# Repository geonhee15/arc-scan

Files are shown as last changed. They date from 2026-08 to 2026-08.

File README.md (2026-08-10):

# ARC Scan

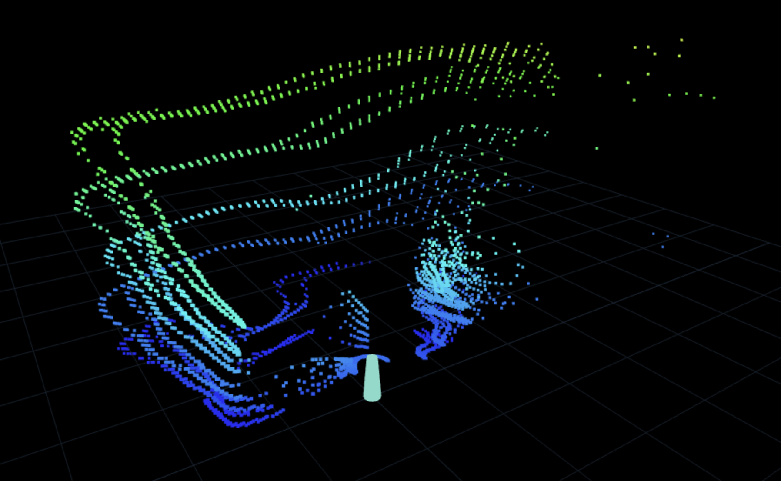
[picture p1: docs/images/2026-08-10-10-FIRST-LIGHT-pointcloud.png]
FIRST LIGHT — 첫 룸 스캔 포인트 클라우드


**A**mbient **R**oom **C**artographer — 회전식 ToF 라이다로 방을 3D 포인트 클라우드로 스캔하는 프로젝트.

VL53L1X ToF 센서 7개를 수직 마스트에 각도를 분산해 장착하고, 서보로 회전시키며
방 전체의 거리 데이터를 수집한다. ESP32가 WiFi 웹소켓으로 스트리밍하고
브라우저에서 three.js로 포인트 클라우드를 실시간 렌더링한다.

## 하드웨어

| 부품 | 수량 | 역할 |
|---|---|---|
| ESP32 DevKit (WROOM-32) | 1 | 메인 컨트롤러 |
| VL53L1X 브레이크아웃 (VL53L0/1XV2 보드) | 7 | ToF 거리 센서 (최대 4m) |
| TCA9548A I2C 멀티플렉서 | 1 | 센서 주소 충돌 해결 (전부 0x29 고정이라 필수) |
| MG996R 서보 | 1 | 회전부 (v1: 180° 스캔) |
| LiPo 503035 500mAh | 1 | 배터리 구동 (마감 단계) |

v2에서 28BYJ-48 스테퍼 + ULN2003A로 교체해 360° 스캔 예정.

## 배선

[docs/wiring.md](docs/wiring.md) 참고.

## 진행 상황

- [x] 0단계: 부품 확인
- [x] 1단계: 센서 1개 + 멀티플렉서 채널 0 인식 성공
- [x] 1단계: 센서 2개 순회 폴링 검증
- [x] 1단계: 7개 전 채널 순회 폴링
- [x] 2단계: WiFi 웹소켓 + three.js 시각화
- [x] 3단계: CAD 설계 완료
- [x] 3단계: 마스트/브라켓 3D 프린팅 + 조립
- [x] 4단계: 풀 조립 스윕 검증 (배선 간섭 없음)
- [x] 4단계: 서보 동기화, 구면좌표 변환, 첫 스캔
- [x] 5단계: 스캔 품질 개선 (1도 스텝 + ROI 4x4)
- [ ] 5단계: 색상 매핑, 배터리 구동, 데모 영상

## 폴더 구조

- `src/` — 단계별 스케치
- `diagnostics/` — 디버깅용 스케치 (I2C 스캐너 등)
- `docs/` — 배선표, 트러블슈팅 기록
- `web/` — 브라우저 뷰어 (three.js)
- `cad/` — 3D 프린팅용 OpenSCAD 소스 + STL

## 삽질 기록

[docs/troubleshooting.md](docs/troubleshooting.md) — 증상 → 원인 → 해결 형식.
같은 보드 조합으로 만드는 사람에게 제일 유용한 문서.

## 빌드 사진

[docs/images/](docs/images/) — 납땜 전 부품부터 채널 검증 시리얼 출력까지 단계별 기록.

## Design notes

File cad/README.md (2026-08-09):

# CAD 파일

OpenSCAD 소스(.scad)가 원본이고 STL은 렌더링 결과물이다.
OpenSCAD는 openscad.org에서 무료 설치. .scad 열어서 상단 변수 수정 →
F6(렌더) → STL 내보내기.

## 파일

- arc_scan_servo_stand.scad / .stl — MG996R 스탠드. 표준 치수 기반이라 **바로 출력 가능**
- arc_scan_mast.scad — 센서 마스트. **실측 4개 값 수정 후 렌더링할 것**
- arc_scan_mast_DEFAULT_DIMS.stl — 미실측 기본값 렌더링. 참고용, 출력 금지

## 마스트 실측 항목 (센서 보드에서 캘리퍼스나 자로)

1. sens_hole_span — 양쪽 나사구멍 중심 간 거리
2. sens_hole_d — 나사구멍 지름 (사용할 나사에 맞게, M2 셀프태핑이면 1.8~2.0)
3. sens_board_len — 보드 긴 변
4. sens_board_wid — 보드 짧은 변

서보 혼 값(horn_*)은 원형 혼 실물 기준으로 확인.

## 출력 설정 권장

- 재료: PLA면 충분
- 레이어: 0.2mm, 인필: 30~40%
- 서보 스탠드: 그대로 바닥에 놓고 출력, 서포트 불필요
- 마스트: 세워서 출력 (바닥 디스크가 베드), 서포트 불필요하게 설계됨.
  틸트면 오버행 최대 30°라 쿨링만 정상이면 깨끗하게 나옴
- 마스트 높이 약 195mm — 출력 시간 수 시간 예상

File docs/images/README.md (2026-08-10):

# 빌드 사진

파일명 형식: 날짜-순번-내용

- 01-xiao-unboxing: XIAO ESP32-C3 개봉 (헤더 미납땜 상태, 이후 WROOM으로 교체)
- 02-vl53l1x-before-solder: VL53L1X 브레이크아웃 납땜 전 (VL53L0/1XV2 공용 기판)
- 03-serial-2ch-success: 2채널 순회 폴링 첫 성공 (천장 ~1720mm)
- 04-breadboard-3ch: 2보드 분리 배치 (컨트롤 보드 + 센서 보드, 3센서)
- 05-serial-3ch-success: 3채널 검증
- 06-serial-4ch-success: 4채널 검증
- 07-serial-5ch-success: 5채널 검증 (복합 배선 버그 해결 직후)
- 08-serial-6ch-success: 6채널 검증 (한 번에 성공)
- 09-breadboard-6ch-full: 6센서 시점 전체 회로 실사 (컨트롤 보드 + 센서 보드 2장 구성)
- 2026-08-10-02-full-assembly: 마스트 완성체 (센서 7개 + 스페이서 + 서보 스탠드, 배선 완료)
- 10-FIRST-LIGHT-pointcloud: 첫 스캔 성공. 방의 벽 모서리, 벽면, 가구, 바닥이
  포인트 클라우드로 재구성됨 (7센서 x 180도 스윕)

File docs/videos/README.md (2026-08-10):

# 빌드 영상

- 2026-08-10-01-mast-first-motion: 마스트 첫 가동. 시리얼 명령(c/각도/s)으로
  서보 위 마스트가 회전하는 최초 동작 확인
- 2026-08-10-02-full-assembly-sweep: 센서 7개 장착 + 배선 완료 상태의 풀 스윕 동작.
  회전 중 배선 간섭 없음 확인
- 2026-08-10-03-first-scan: 첫 스캔 실시간 영상 (스캔 동작 + 뷰어에 점 쌓이는 장면)

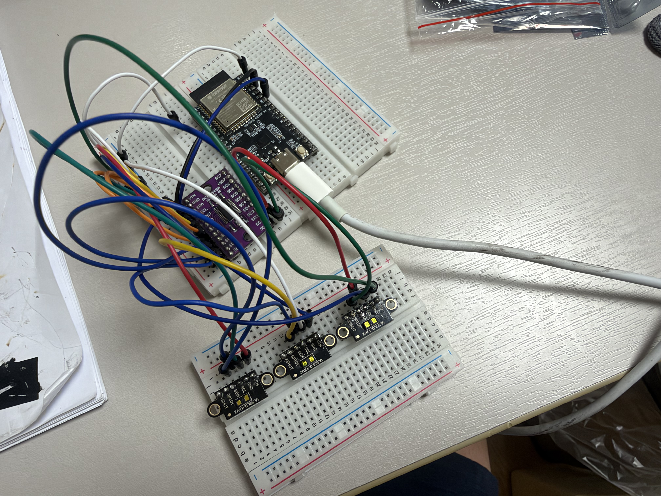
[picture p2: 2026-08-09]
docs/images/2026-08-09-04-breadboard-3ch.jpeg

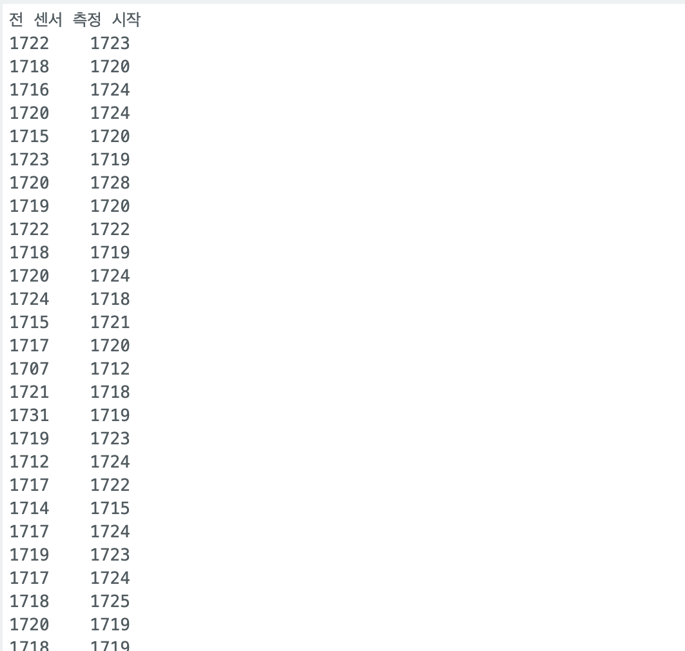
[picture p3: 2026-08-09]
docs/images/2026-08-09-03-serial-2ch-success.png

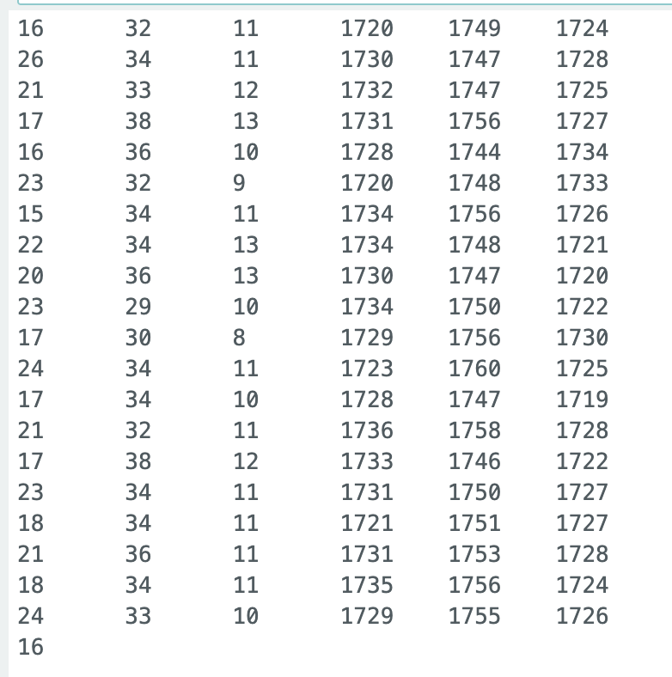
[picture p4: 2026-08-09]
docs/images/2026-08-09-08-serial-6ch-success.png

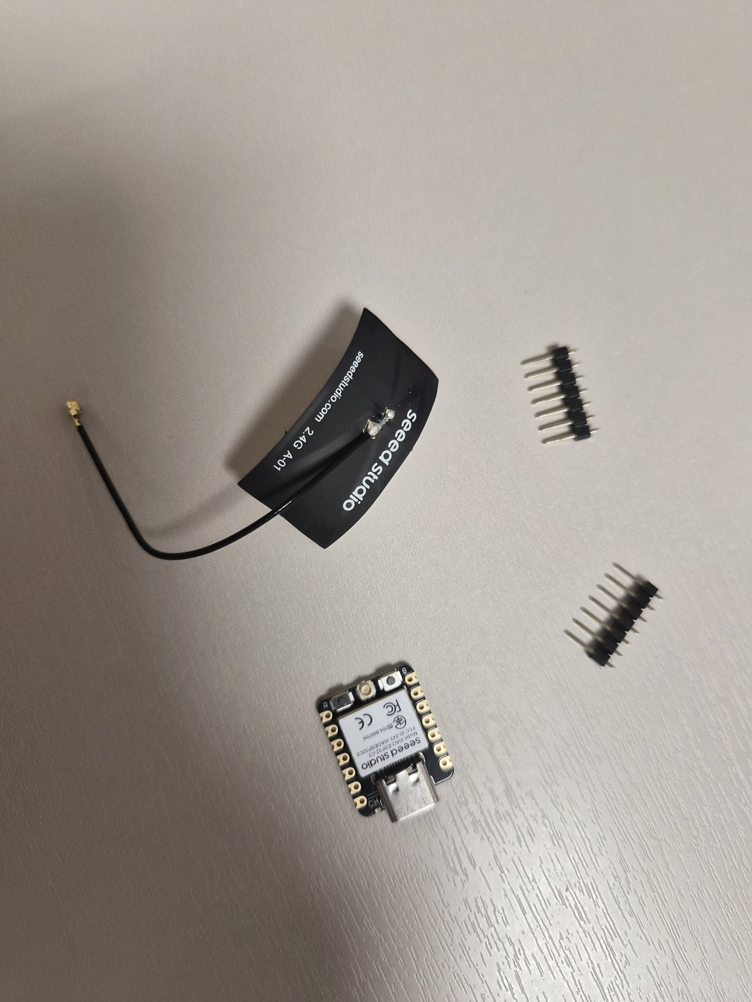
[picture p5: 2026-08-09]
docs/images/2026-08-09-01-xiao-unboxing.jpeg

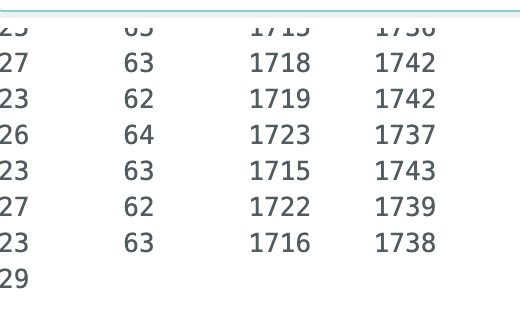
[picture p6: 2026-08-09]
docs/images/2026-08-09-06-serial-4ch-success.png

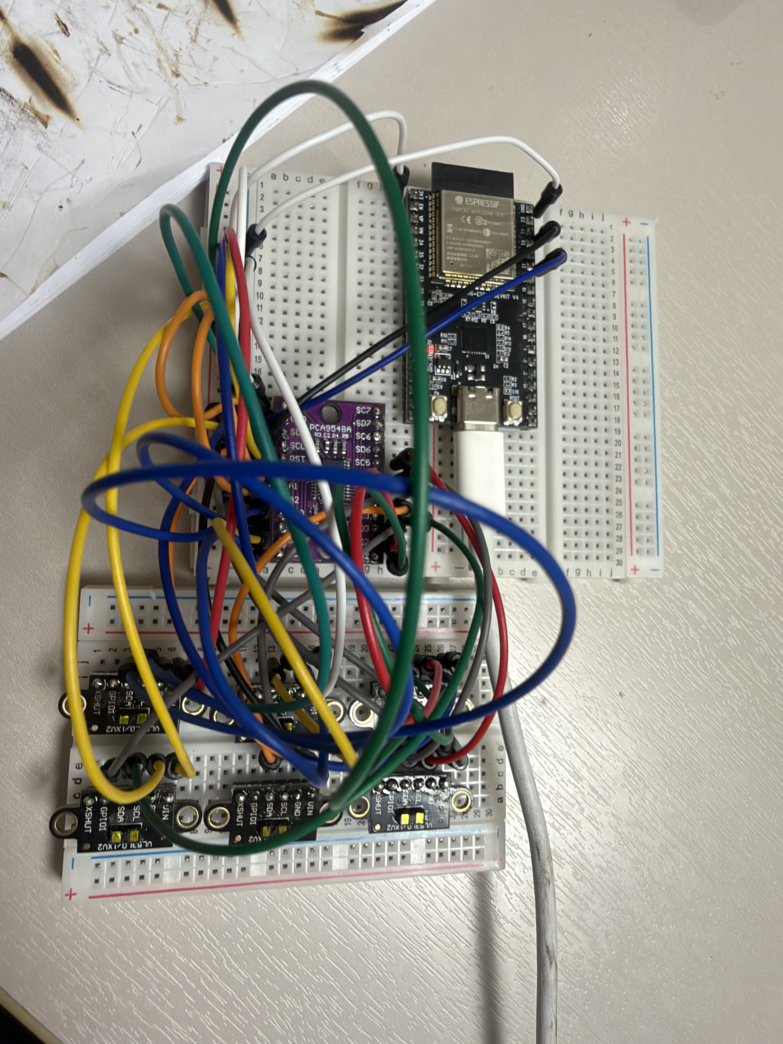
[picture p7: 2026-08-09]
docs/images/2026-08-09-09-breadboard-6ch-full.jpeg

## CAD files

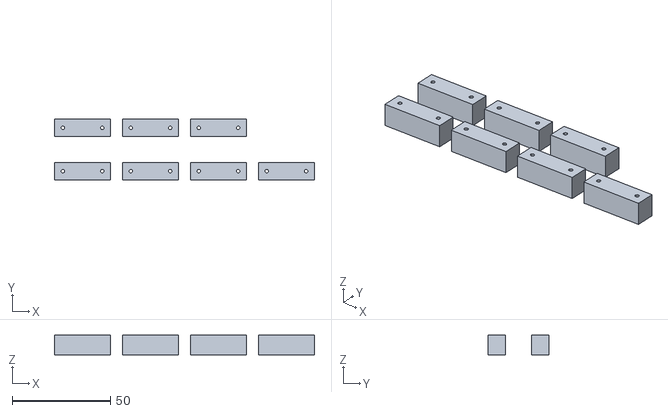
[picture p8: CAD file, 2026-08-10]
cad/arc_scan_sensor_spacer_x7.stl
132.0 x 31.0 x 10.0

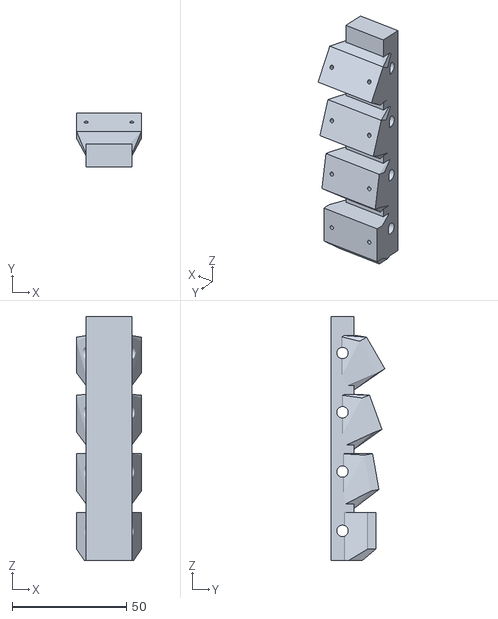
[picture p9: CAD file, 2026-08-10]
cad/arc_scan_mast_TOP.stl
28.5 x 23.6 x 107.0

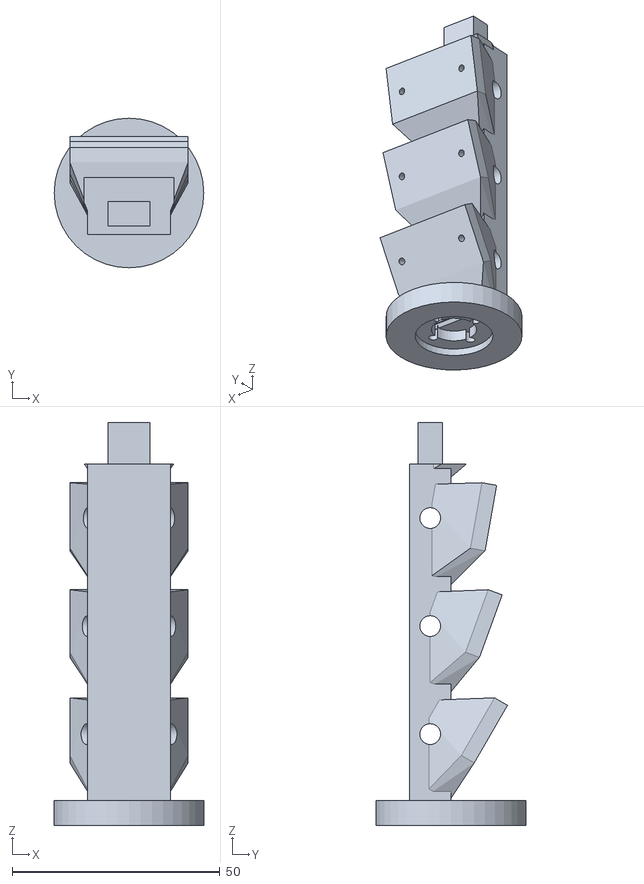
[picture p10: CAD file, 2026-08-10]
cad/arc_scan_mast_BOTTOM.stl
36.0 x 36.0 x 97.0

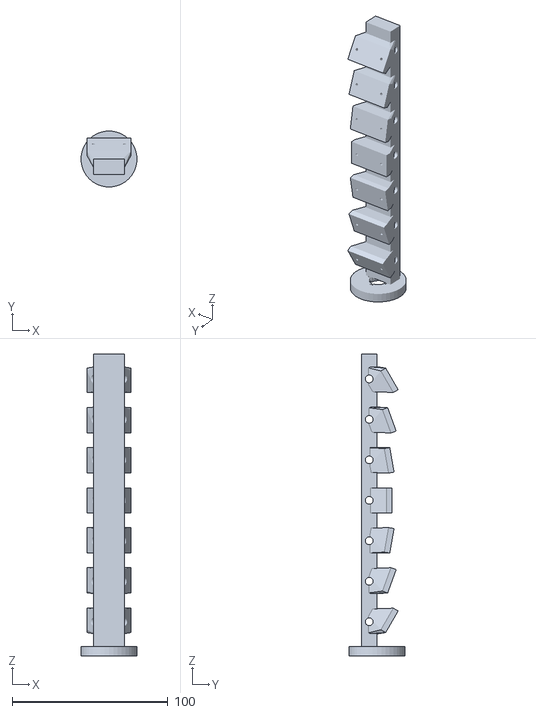
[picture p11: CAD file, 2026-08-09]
cad/arc_scan_mast_MEASURED.stl
36.0 x 36.0 x 194.0

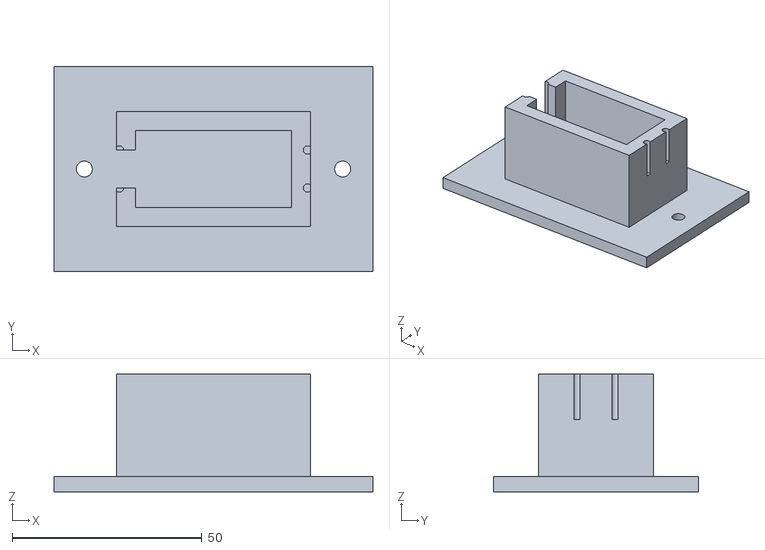
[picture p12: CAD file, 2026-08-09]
cad/arc_scan_servo_stand.stl
84.0 x 54.0 x 31.0

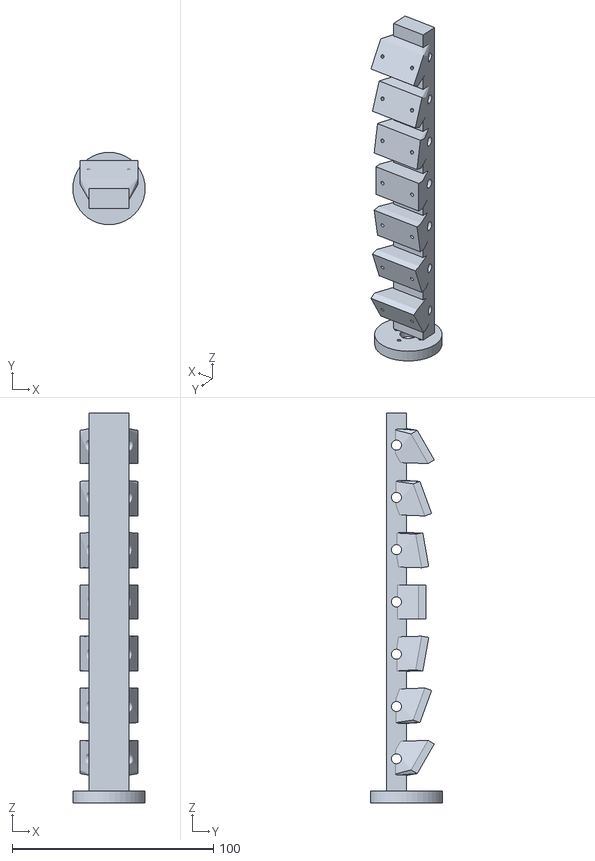
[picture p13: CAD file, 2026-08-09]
cad/arc_scan_mast_DEFAULT_DIMS.stl
36.0 x 36.0 x 194.0

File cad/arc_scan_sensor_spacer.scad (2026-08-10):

// ARC Scan - 센서 스페이서 (헤더 핀 간섭 해결)
// 보드 뒷면과 마스트 장착면 사이에 끼움. 헤더 핀 줄이 지나는 자리에 골.
// 조립: 센서 → M2로 스페이서에 고정 (스페이서 파일럿에 태핑),
//       스페이서 뒷면 → 마스트 장착면에 글루건 접착

$fn = 32;

// 마스트와 동일 실측값
sens_hole_span = 20.0;
sens_board_len = 24.5;
sens_board_wid = 10.0;

spacer_t   = 10;    // 두께 (헤더 핀 길이보다 크게)
pad        = 4;     // 보드보다 큰 여유
chan_w     = 7;     // 헤더 골 폭
pilot_d    = 1.8;   // M2 태핑 파일럿

w = sens_board_len + pad;   // 28.5
h = sens_board_wid + 6;     // 16 (장착면과 동일)

// 7개 한 판에
for (ix = [0:3]) for (iy = [0:1]) {
  n = ix + iy*4;
  if (n < 7)
    translate([ix*(w+6), iy*(h+6), 0])
    difference() {
      cube([w, h, spacer_t]);
      // 헤더 골: 아래쪽 긴 변을 따라 관통
      translate([-1, -1, -1]) cube([w+2, chan_w+1, spacer_t+2]);
      // 파일럿 구멍 2개 (보드 구멍 위치 = 세로 중앙 기준)
      for (s = [-1, 1])
        translate([w/2 + s*sens_hole_span/2, chan_w + (h-chan_w)/2, -1])
          cylinder(d = pilot_d, h = spacer_t+2);
    }
}

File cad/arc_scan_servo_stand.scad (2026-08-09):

// ARC Scan - MG996R 서보 스탠드
// 서보를 출력축이 위를 보게 세워서 고정하는 받침대
// MG996R 표준 치수 기반. 출력 전 본인 서보 실측으로 아래 변수 확인 권장

$fn = 48;

// ===== 실측 확인 변수 =====
servo_len   = 40.7;   // 서보 몸통 길이 (플랜지 제외)
servo_wid   = 20.0;   // 서보 몸통 폭
clearance   = 0.4;    // 끼움 여유
hole_span_l = 49.5;   // 플랜지 나사구멍 간격 (긴 방향, 대각 아님)
hole_span_w = 10.0;   // 플랜지 나사구멍 간격 (짧은 방향)
flange_h    = 27.0;   // 몸통 바닥에서 플랜지 아랫면까지 높이
screw_d     = 2.2;    // 나사 구멍 지름 (M2.5 셀프태핑 기준)

// ===== 스탠드 형상 =====
base_w = 84; base_d = 54; base_t = 4;   // 바닥판
body_w = servo_len + clearance;
body_d = servo_wid + clearance;
wall   = 5;

difference() {
  union() {
    // 바닥판
    translate([-base_w/2, -base_d/2, 0]) cube([base_w, base_d, base_t]);
    // 서보 포켓 벽체 (플랜지가 벽 윗면에 얹힘)
    translate([-(body_w/2+wall), -(body_d/2+wall), 0])
      cube([body_w + 2*wall, body_d + 2*wall, base_t + flange_h]);
  }
  // 서보 몸통 관통 포켓
  translate([-body_w/2, -body_d/2, base_t])
    cube([body_w, body_d, flange_h + 1]);
  // 케이블 빠져나갈 홈
  translate([-body_w/2 - wall - 1, -5, base_t])
    cube([wall + 2, 10, flange_h + 1]);
  // 플랜지 나사 파일럿 구멍 4개
  for (sx = [-1, 1]) for (sy = [-1, 1])
    translate([sx*hole_span_l/2, sy*hole_span_w/2, base_t + flange_h - 12])
      cylinder(d = screw_d, h = 13);
  // 바닥 고정용 구멍 (책상 클램프/나사, 선택)
  for (sx = [-1, 1])
    translate([sx*(base_w/2 - 8), 0, -1]) cylinder(d = 4.2, h = base_t + 2);
}

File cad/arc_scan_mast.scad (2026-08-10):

// ARC Scan - 센서 마스트 (7단 틸트 장착면)
// 채널 0 = 최상단 +30°(위쪽 응시), 채널 6 = 최하단 -30°(아래쪽 응시), 10° 간격
// 장착면은 세로판이며 면의 법선이 전방(+Y)에서 위아래로 틸트됨
// 센서 보드는 장착면에 M2 셀프태핑 2개로 고정, 렌즈가 전방을 바라봄
//
// ★ 출력 전 반드시 실측해서 아래 [실측 필수] 4개 값 수정할 것 ★

$fn = 40;

// ===== [실측 필수] 센서 보드 =====
sens_hole_span = 20.0;
sens_hole_d    = 1.8;
sens_board_len = 24.5;
sens_board_wid = 10.0;

// ===== [실측 권장] 서보 혼 =====
horn_dia          = 20.0;
horn_screw_circle = 14.0;
horn_screw_d      = 2.4;  // 마스트 관통용 (나사는 혼 구멍에 태핑됨)
horn_screw_n      = 4;

// ===== 마스트 형상 =====
tilts      = [30, 20, 10, 0, -10, -20, -30]; // 채널 0(위) → 6(아래)
level_step = 26;     // 장착면 세로 간격
spine_w    = 20;     // 기둥 폭
spine_d    = 10;     // 기둥 두께 (Y)
plate_w    = sens_board_len + 4;   // 장착면 폭
plate_h    = sens_board_wid + 6;   // 장착면 높이
plate_t    = 3.6;    // 장착면 두께
standoff   = 6;      // 기둥 전면에서 장착면까지 거리
base_dia   = 36;
base_t     = 6;
mast_h     = base_t + level_step * 7 + 6;

// --- 세로 장착판: 면 중심이 원점, 법선 +Y, 구멍은 Y로 관통
module face_plate() {
  difference() {
    translate([-plate_w/2, -plate_t, -plate_h/2])
      cube([plate_w, plate_t, plate_h]);
    for (s = [-1, 1])
      translate([s * sens_hole_span/2, -plate_t - 1, 0])
        rotate([-90, 0, 0]) cylinder(d = sens_hole_d, h = plate_t + 2);
  }
}

module mast_body() {
  // 바닥 디스크 (서보 혼 결합)
  difference() {
    cylinder(d = base_dia, h = base_t);
    translate([0, 0, -0.01]) cylinder(d = horn_dia + 0.6, h = 2);
    translate([0, 0, -1]) cylinder(d = 12, h = base_t + 2); // 허브 통과
    for (a = [0 : 360/horn_screw_n : 359])
      rotate([0, 0, a]) translate([horn_screw_circle/2, 0, -1])
        cylinder(d = horn_screw_d, h = base_t + 2);
  }
  // 기둥
  translate([-spine_w/2, -spine_d, base_t])
    cube([spine_w, spine_d, mast_h - base_t]);
  // 7단: 틸트 장착판 + 기둥과 잇는 hull 웨지
  for (i = [0 : 6]) {
    z = base_t + level_step * (7 - i) - level_step/2 + 3;
    hull() {
      translate([0, standoff + plate_t, z]) rotate([tilts[i], 0, 0]) face_plate();
      translate([-spine_w/2 + 2, -spine_d + 1, z - plate_h/2 - 9])
        cube([spine_w - 4, spine_d - 2, plate_h + 9]);  // 아래로 연장: 웨지 밑면 경사를 세워 오버행 완화
    }
  }
}

// hull이 구멍을 메우므로 전체에서 구멍 재차감
module full_mast() {
difference() {
  mast_body();
  for (i = [0 : 6]) {
    z = base_t + level_step * (7 - i) - level_step/2 + 3;
    // 센서 나사 구멍 (틸트 방향 그대로 관통)
    translate([0, standoff + plate_t, z]) rotate([tilts[i], 0, 0])
      for (s = [-1, 1])
        translate([s * sens_hole_span/2, -plate_t - 8, 0])
          rotate([-90, 0, 0]) cylinder(d = sens_hole_d, h = plate_t + 16);
    // 배선 통과 구멍 (기둥 좌우 관통)
    translate([0, -spine_d/2, z]) rotate([0, 90, 0])
      cylinder(d = 5, h = spine_w + 4, center = true);
  }
}
}

// ===== 분할 출력 =====
// part: "full" | "bottom" | "top"  — 상/하 분할로 출력 높이를 절반으로
part   = "bottom";
z_cut  = 87;          // 분할 높이 (4단과 5단 사이 기둥 구간)
plug_w = 10; plug_d = 6; plug_h = 10;  // 결합 플러그 (하단에 돌출)
gap    = 0.3;         // 소켓 여유 (한쪽)

module plug_shape(extra=0, hextra=0)
  translate([-(plug_w+extra)/2, -spine_d/2 - (plug_d+extra)/2, 0])
    cube([plug_w+extra, plug_d+extra, plug_h+hextra]);

if (part == "full") full_mast();

if (part == "bottom") {
  intersection() { full_mast(); translate([-100,-100,-1]) cube([200,200,z_cut+1]); }
  translate([0,0,z_cut]) plug_shape();          // 위로 솟은 플러그
}

if (part == "top") {
  // 절단면이 베드에 닿게 z_cut만큼 내림, 바닥면에 소켓 파기
  difference() {
    translate([0,0,-z_cut])
      intersection() { full_mast(); translate([-100,-100,z_cut]) cube([200,200,200]); }
    translate([0,0,-0.01]) plug_shape(extra=2*gap, hextra=0.4);
  }
}

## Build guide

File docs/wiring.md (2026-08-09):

# 배선표

## 1단계: WROOM + TCA9548A + 센서 1개 (채널 0)

전원은 전부 3.3V. **5V 금지** (TCA, 센서 모두).

### 전원 레일

| 연결 | 대상 |
|---|---|
| WROOM 3V3 | 브레드보드 빨간(+) 레일 |
| WROOM GND | 파란(−) 레일 |

### TCA9548A

| TCA 핀 | 연결 |
|---|---|
| VIN | 빨간 레일 (3.3V) |
| GND | 파란 레일 |
| A0, A1, A2 | 전부 파란 레일 → 주소 0x70 고정 |
| SDA | WROOM GPIO21 |
| SCL | WROOM GPIO22 |

### VL53L1X (채널 0)

| 센서 핀 | 연결 |
|---|---|
| VIN | 빨간 레일 (3.3V) |
| GND | 파란 레일 |
| SCL | TCA SC0 |
| SDA | TCA SD0 |
| GPIO1, XSHUT | 미연결 |

⚠️ 이 센서 보드는 핀 인쇄 순서가 **VIN, GND, SCL, SDA** 순.
SCL이 SDA보다 먼저라 교차 실수하기 딱 좋음 (실제로 한 번 함, troubleshooting.md 참고).

## 예정 (7센서 확장 시)

센서 2~7을 SD1/SC1 ~ SD6/SC6에 동일 방식으로 추가.
채널 번호 = 마스트 위치 매핑: 채널 0 = 최상단 +30°, 채널 6 = 최하단 −30°, 10° 간격.

## 예정 (서보)

| MG996R | 연결 |
|---|---|
| 빨강 | WROOM VIN (USB 5V) |
| 갈색 | 파란 레일 (GND 공통 필수) |
| 주황 (신호) | GPIO13 |

서보 구동 시 전류 스파이크로 보드 리셋되면 서보 전원만 외부 5V로 분리.

### VL53L1X (채널 1) — 채널 0과 동일 패턴

| 센서 핀 | 연결 |
|---|---|
| VIN | 빨간 레일 (3.3V) |
| GND | 파란 레일 |
| SCL | TCA SC1 |
| SDA | TCA SD1 |
| GPIO1, XSHUT | 미연결 |

검증: 두 채널 모두 천장 거리 ~1720mm 일치 출력 확인 (2026-08-09)

### VL53L1X (채널 2) — 동일 패턴, 센서 전용 브레드보드로 분리

센서 3개째부터 두 번째 브레드보드에 센서 전용 배치.
보드 1(WROOM+TCA)의 전원 레일에서 점퍼선 2가닥으로 보드 2 레일 연장,
센서들의 VIN/GND는 보드 2 레일에서 공급.

| 센서 핀 | 연결 |
|---|---|
| VIN / GND | 보드 2 레일 (보드 1에서 연장) |
| SCL | TCA SC2 |
| SDA | TCA SD2 |

검증: 3채널 모두 천장 ~1710~1725mm 일치 (2026-08-09)

### VL53L1X (채널 5, 6) — 동일 패턴

| 센서 | SCL | SDA |
|---|---|---|
| 채널 5 | TCA SC5 | TCA SD5 |
| 채널 6 | TCA SC6 | TCA SD6 |

검증: 7채널 전부 동시 폴링 정상 (2026-08-09). **1단계 완료.**

### 서보 전원 구성 (확정)

| MG996R | 연결 |
|---|---|
| 주황 (신호) | WROOM GPIO13 |
| 빨강 (전원) | 외부 5V (폰 충전기 2A, USB 케이블 개조) — **WROOM VIN 아님** |
| 갈색 (GND) | 브레드보드 GND 레일 (충전기 GND와 공통 접지) |

USB 단일 전원으로는 brownout 발생 (troubleshooting.md 참고).

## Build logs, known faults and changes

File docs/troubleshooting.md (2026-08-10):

# 트러블슈팅 기록

증상 → 원인 → 해결 형식. 날짜순.

## 2026-08-09

### 납땜 브릿지 (XIAO, 센서 헤더)

- **증상**: 납땜 시 옆 핀끼리 납이 계속 붙음
- **원인**: 납 공급량 과다 + 인두를 오래 대고 있음
- **해결**: 납량을 절반 이하로 줄이고, 납선이 녹기 시작하면 1초 안에 뗌.
  이미 붙은 브릿지는 깨끗한 맨 팁으로 핀 사이를 긁어내리면 갈라짐.
  다음 구매: 솔더윅, 플럭스 펜, 0.6~0.8mm 납선

### 센서 초기화 실패

- **증상**: `sensor.init()` 실패, "센서 초기화 실패! 배선 확인" 출력
- **진단**: I2C 스캐너(diagnostics/i2c_scan)로 단계 분리.
  메인 버스에서 0x70(TCA) 발견 → WROOM↔TCA 구간 정상.
  채널 0 열고 0x29 응답 없음 → TCA↔센서 구간 문제로 특정
- **원인**: 센서 보드 핀 순서가 VIN, GND, **SCL, SDA**인데
  SDA/SCL을 교차해서 연결함
- **해결**: 센서 SCL↔TCA SC0, 센서 SDA↔TCA SD0으로 교정
- **교훈**: 브레이크아웃 보드마다 핀 순서 다름. 인쇄 글자 기준으로 연결할 것

### 메모

- 센서 보드 실크가 "VL53L0/1XV2" — L0X/L1X 공용 기판이라 칩 종류는
  코드로 판별해야 함. L1X 라이브러리 init 성공 여부로 확인 예정

### 채널 1 초기화 실패 (센서 2개째 추가 시)

- **증상**: `채널 1 초기화 실패!` — 채널 0은 정상 통과
- **범위 특정**: 채널 0 통과 = WROOM/TCA/코드 정상 → 새로 추가한
  채널 1 라인(배선, 납땜, 센서)만 조사
- **원인/해결**: 두 번째 센서 라인 배선 문제 확인 후 교정, 재실행으로 해결
- **교훈**: 센서를 하나씩 추가하면 실패 시 용의자가 방금 추가한 라인
  하나로 좁혀진다. 7개 한 번에 꽂았으면 못 찾았을 것

### 측정값 0의 의미

- **증상**: 센서를 손으로 가리거나 렌즈에 밀착 시 0 또는 한 자리 수 출력
- **원인**: 고장 아님. VL53L1X는 측정 실패(범위 이탈, 반사 부족)를 0으로 반환
- **처리 방침**: 스캔 파이프라인에서 0은 무효 포인트로 버린다 (포인트 클라우드 미포함)

### 채널 4 초기화 실패 — 복합 원인 (2연타 버그)

- **증상**: `채널 4 초기화 실패!`. 센서 맞교환 테스트로 센서는 무죄,
  채널 4 경로 문제로 특정. 그런데 배선을 고쳐도 계속 실패
- **원인 A**: 채널 4 배선이 ESP32 핀과 같은 가로줄에 꽂혀 있었음 (SD5 라인 충돌)
- **원인 B**: A를 고치려고 ESP32 위치를 옮기는 과정에서 GPIO21에 SCL,
  GPIO22에 SDA를 교차로 재연결 (2차 사고)
- **해결**: A 교정 후에도 실패 → 수리 중 건드린 부분을 재점검 → B 발견, 교정 후 5채널 정상
- **교훈**:
  1. 원인이 2개 겹치면 하나를 고쳐도 증상이 그대로라 "고친 게 맞나"를 의심하게 됨.
     고쳤는데도 안 되면, 고치면서 새로 건드린 곳부터 의심할 것
  2. 부품을 옮겨 꽂으면 그 부품의 기존 배선 전체가 재검증 대상이 된다

## 2026-08-10

### Brownout detector was triggered (서보 기동 시 리셋)

- **증상**: 서보 스윕 시작 순간 시리얼에 `Brownout detector was triggered` 출력 후
  ESP32 재부팅 반복
- **원인**: MG996R 기동전류(1A+)를 USB 5V(WROOM VIN 경유)가 감당 못 해
  순간 전압 강하 → ESP32 저전압 보호 리셋
- **해결**: 서보 전원 분리. USB 케이블을 잘라 폰 충전기(2A)에서 5V/GND를 따고,
  서보 빨강은 충전기 5V로, 충전기 GND는 브레드보드 GND 레일에 연결해 공통 접지.
  신호선(GPIO13)은 그대로
- **핵심**: 전원이 두 계통이어도 GND는 반드시 하나로 묶는다. GND 미공유 시
  서보 오동작(떨림/무반응)
- **켜는 순서**: 충전기 먼저 → WROOM USB. 해제는 역순

### 마스트 단일 출력 실패 (최상단 부근)

- **증상**: 마스트 단일 출력 시 최상단 부근에서 2회 연속 실패
- **대응**: 상하 2피스 분할(97+107mm) + 플러그/소켓 결합으로 재설계

### 서보 플랜지 구멍 미정렬 (조립)

- **증상**: 서보 플랜지 구멍이 표준(49.5mm)보다 바깥이라 스탠드 파일럿과 미정렬
- **대응**: 나사 생략, 포켓 밀착 고정으로 진행 (필요시 케이블타이 보강).
  마스트-혼 결합은 M2 대신 글루건 사용

### 센서 헤더 핀 간섭 (조립)

- **증상**: 센서 헤더 핀이 뒷면으로 돌출되어 장착면에 평면 밀착 불가 (마스트 설계 누락)
- **해결**: 10mm 스페이서 삽입 (헤더 골 포함), 센서-스페이서 나사 결합 +
  스페이서-마스트 글루건 접착

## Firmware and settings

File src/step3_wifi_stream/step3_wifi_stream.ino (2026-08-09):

// ARC Scan - 3단계: WiFi 웹소켓으로 7채널 거리 스트리밍
// 보드: ESP32 Dev Module (WROOM-32)
// 라이브러리: VL53L1X by Pololu, WebSockets by Markus Sattler (links2004)
//
// 사용법:
// 1. 아래 WIFI_SSID / WIFI_PASS를 집 와이파이로 수정 (2.4GHz만 지원, 5GHz 안 됨)
// 2. 업로드 후 시리얼 모니터에 뜨는 IP 주소 확인
// 3. web/viewer.html을 브라우저로 열고 그 IP 입력
// ※ 실제 와이파이 비밀번호를 넣은 파일은 커밋하지 말 것 (리포엔 플레이스홀더 유지)

#include <WiFi.h>
#include <WebSocketsServer.h>
#include <Wire.h>
#include <VL53L1X.h>

const char* WIFI_SSID = "여기에_와이파이_이름";
const char* WIFI_PASS = "여기에_비밀번호";

#define TCA_ADDR 0x70
#define NUM_SENSORS 7
#define SEND_INTERVAL_MS 50   // 브라우저로 20Hz 전송

VL53L1X sensors[NUM_SENSORS];
uint16_t latest[NUM_SENSORS] = {0};
WebSocketsServer webSocket(81);
unsigned long lastSend = 0;

void tcaSelect(uint8_t ch) {
  Wire.beginTransmission(TCA_ADDR);
  Wire.write(1 << ch);
  Wire.endTransmission();
}

void setup() {
  Serial.begin(115200);
  delay(2000);
  Wire.begin();

  // 센서 초기화
  for (uint8_t i = 0; i < NUM_SENSORS; i++) {
    tcaSelect(i);
    sensors[i].setTimeout(500);
    if (!sensors[i].init()) {
      Serial.print("채널 ");
      Serial.print(i);
      Serial.println(" 초기화 실패!");
      while (1);
    }
    sensors[i].setDistanceMode(VL53L1X::Long);
    sensors[i].setMeasurementTimingBudget(50000);
    sensors[i].startContinuous(50);
  }
  Serial.println("전 센서 측정 시작");

  // WiFi 연결
  WiFi.begin(WIFI_SSID, WIFI_PASS);
  Serial.print("WiFi 연결 중");
  while (WiFi.status() != WL_CONNECTED) {
    delay(500);
    Serial.print(".");
  }
  Serial.println();
  Serial.print("연결됨! 뷰어에 입력할 IP: ");
  Serial.println(WiFi.localIP());

  webSocket.begin();
}

void loop() {
  webSocket.loop();

  // 준비된 센서만 논블로킹으로 읽어 최신값 갱신
  for (uint8_t i = 0; i < NUM_SENSORS; i++) {
    tcaSelect(i);
    if (sensors[i].dataReady()) {
      latest[i] = sensors[i].read(false);
    }
  }

  // 20Hz로 JSON 브로드캐스트: {"d":[d0,...,d6]}
  if (millis() - lastSend >= SEND_INTERVAL_MS) {
    lastSend = millis();
    String json = "{\"d\":[";
    for (uint8_t i = 0; i < NUM_SENSORS; i++) {
      json += latest[i];
      if (i < NUM_SENSORS - 1) json += ",";
    }
    json += "]}";
    webSocket.broadcastTXT(json);
  }
}

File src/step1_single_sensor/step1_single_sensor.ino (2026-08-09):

// ARC Scan - 1단계: TCA9548A 채널 0의 VL53L1X 1개 읽기
// 보드: ESP32 Dev Module (WROOM-32)
// 라이브러리: VL53L1X by Pololu

#include <Wire.h>
#include <VL53L1X.h>

#define TCA_ADDR 0x70   // A0~A2 전부 GND일 때

VL53L1X sensor;

// 멀티플렉서 채널 선택
void tcaSelect(uint8_t ch) {
  Wire.beginTransmission(TCA_ADDR);
  Wire.write(1 << ch);
  Wire.endTransmission();
}

void setup() {
  Serial.begin(115200);
  delay(2000);
  Wire.begin();   // WROOM 기본: SDA=21, SCL=22

  tcaSelect(0);

  sensor.setTimeout(500);
  if (!sensor.init()) {
    Serial.println("센서 초기화 실패! 배선 확인");
    while (1);
  }

  sensor.setDistanceMode(VL53L1X::Long);      // 최대 4m
  sensor.setMeasurementTimingBudget(50000);   // 측정당 50ms
  sensor.startContinuous(50);
  Serial.println("측정 시작");
}

void loop() {
  tcaSelect(0);
  uint16_t mm = sensor.read();
  if (sensor.timeoutOccurred()) {
    Serial.println("타임아웃");
  } else {
    Serial.println(mm);
  }
}

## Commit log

2026-08-09 1단계: 센서 1개 + 멀티플렉서 채널 0 인식, 초기 리포 구성
2026-08-09 2단계: 센서 2개 채널 순회 폴링 성공
2026-08-09 2단계: 센서 3개 검증, 센서 전용 보드 분리
2026-08-09 docs: 빌드 사진 6장 추가 (납땜 전 ~ 4채널 검증)
2026-08-09 2단계: 센서 5개 검증, 복합 배선 버그(라인 충돌+SDA/SCL 교차) 해결
2026-08-09 2단계: 센서 6개 검증 + 빌드 사진 추가
2026-08-09 1단계 완료: 7채널 검증 + 3단계 WiFi 스트리밍/뷰어 추가
2026-08-09 3단계: 서보 스탠드 + 센서 마스트 CAD (OpenSCAD 파라메트릭)
    [arc_scan_mast.scad, arc_scan_mast_DEFAULT_DIMS.stl, arc_scan_servo_stand.scad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]
2026-08-09 3단계: 마스트 실측 치수 반영 (구멍간 20mm, M2 파일럿 1.8mm)
    [arc_scan_mast.scad, arc_scan_mast_MEASURED.stl]
2026-08-09 3단계: 혼 허브 간섭 수정 (12구멍 원형 혼 대응)
    실제 수정 내용(허브 통과 구멍 ø12, 혼 나사 관통 2.4mm)은 직전 커밋에 이미 포함됨.
    이력 기록용 커밋.
2026-08-09 4a단계: 서보 검증 완료, brownout 해결 (서보 전원 분리)
2026-08-10 2단계: WiFi 웹소켓 + three.js 시각화 성공
2026-08-10 3단계: 마스트 2피스 분할 버전 (고높이 출력 실패 대응)
    [arc_scan_mast.scad, arc_scan_mast_BOTTOM.stl, arc_scan_mast_TOP.stl]
2026-08-10 3단계 완료: 마스트 조립 및 첫 가동
2026-08-10 3단계: 센서 스페이서 추가 (헤더 핀 간섭 해결)
    [arc_scan_sensor_spacer.scad, arc_scan_sensor_spacer_x7.stl]
2026-08-10 4단계: 풀 조립 스윕 검증 (배선 간섭 없음)
2026-08-10 4단계 완료: FIRST LIGHT - 첫 룸 스캔 성공
2026-08-10 4c: 고품질 스캔 (1도 스텝 + ROI 4x4)
